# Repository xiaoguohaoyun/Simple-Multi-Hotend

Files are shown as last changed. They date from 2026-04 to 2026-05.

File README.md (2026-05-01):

# [Simple-Multi-Hotend]

[Simple-Multi-Hotend]是一种FDM3D打印多材料/多色解决方案。通过在打印打印过程中切换预热好的装载不同耗材的热端实现快速多材料打印。其目标是实现尽可能低成本且简单稳定的多材料打印，为了实现较高的适配性，热端切换只需要打印头XY轴运动就可实现，且切换结构与热端无关，可以通过修改热端固定件等实现其他热端的兼容。
打印头

QQ20260404-193802

---

## 核心特性
- **自动预热**：开启orcaslicer中的Ooze预防功能，会根据自己设定的预热时间提前在切换材料前插入预热命令，切换时释放旧热端并切换到待机温度然后抓取已经预热好的热端，若下一次切换的时间短于加热时间则保持温度不降温。
- **欠驱动切换机构**：采用欠驱动设计不需要额外增加主动元件，利用打印头自身的XY轴运动与停靠坞机械交互来实现热端切换和耗材丝夹紧松开。
- **磁吸麦克斯韦定位耦合机构**：热端模块锁定采用N52磁铁磁吸配合[麦克斯韦耦合](https://en.wikipedia.org/wiki/Kinematic_coupling)定位机构，打印头端有定位销组成的三个槽口，热端模块端有圆头销头部组成的球头。磁吸配合时实现对热端模块空间六自由度的限位，不存在过定位所以即使有加工装配误差以及磨损变形热端模块都能自适应消隙精确定位。
- **自动喷嘴偏移量校准**:采用喷嘴触碰校准器校准每个头XYZ轴相对T0的偏移量，参考[FoxChanger](https://github.com/Noisyfox/FoxChanger/tree/main/NozzleProbe)，需要清理干净喷嘴才能获得正确喷嘴偏移量。不需要每次打印前都校准，通常在刚装配好或者出现撞头等情况需要校准。

## 硬件与软件需求

### 硬件
* **打印机** 原理上支持打印头具有XY移动能力的机型（如voron2.4、voron三叉戟、大鱼TT等），本开源只提供打印头和基础停靠坞设计需要根据自己机型固定装载停靠坞的铝型材和其他兼容修改。
* **主板** 由于采用有线加热，每个热端模块具有一个加热片和热敏，可利用主板空余接口来扩展少量热端模块，若需要扩展更多热端模块需要制作[扩展板]( https://oshwhub.com/johnnybyzhang/f103-based-klipper-ext-can-usb)来增加主板的加热棒接口和热敏接口。

### 软件
* **固件** 整体热端切换通过klipper宏命令实现，若需使用喷嘴偏移量校准则需要下载[toolchange](https://github.com/viesturz/klipper-toolchanger)插件，配合自动校准宏来实现。
* **切片软件**：采用Orcaslicer，其他切片软件可自行探索。

## 组成概览

### 组成部分
- 打印头：有除了热端以外的其他部分
- 热端模块：包含热端，接有铁氟龙管和加热片和热敏的线
- 停靠坞：用于存放停靠的热端，可以堵住停靠热端的嘴防止漏料，以及有散热风扇给停靠的热端进行散热（无封箱的采用侧面离心风扇对所有热端进行散热、有封箱的采用每个停靠坞一个轴流风扇）。

### 零件
#### 打印版
- 1.5×5（直径*长）圆柱销：用于构成麦克斯韦耦合定位的槽（×6）
- 3×6（直径*长）圆头销：用于构成麦克斯韦耦合定位的球（一个热端3个）
- 5×20（直径*长）内螺纹圆头销：装配于停靠坞上用于撑开挤出机摆臂（一个停靠坞1个）
- 6×4（直径*厚）N52磁铁：用于吸附热端模块到打印头上和停靠坞上（一个热端3个，一个停靠坞1个，打印头3个）
- M3×6沉头螺丝
- M3×25螺丝
- M3×8螺丝
- M3×10螺丝
- M3×12螺丝
- M3×14螺丝
- M3×20螺丝
- M2.5×16螺丝
- M2×8螺丝
- M3×4×4热熔螺母
- HGX挤出机齿轮组
- 4020蜗轮风扇
- 2510轴流风扇
- 欧姆龙微动开关
- 10×2（宽×厚）自粘耐热硅胶条
#### CNC版
CNC件采用嘉立创打样制作（打样零件汇总在CAD文件夹里）
- 1.5×5（直径*长）圆柱销：用于构成麦克斯韦耦合定位的槽（×6）
- 3×5（直径*长）圆头销：用于构成麦克斯韦耦合定位的球（一个热端3个）
- 5×20（直径*长）内螺纹圆头销：装配于停靠坞上用于撑开挤出机摆臂（一个停靠坞1个）
- 6×4（直径*厚）N52磁铁：用于吸附热端模块到打印头上和停靠坞上（一个热端3个，一个停靠坞1个，打印头3个）
- M3×8沉头螺丝
- M3×25螺丝
- M3×8螺丝
- M3×10螺丝
- M3×12螺丝
- M3×14螺丝
- M3×20螺丝
- M2.5×16螺丝
- M2×8螺丝
- M4长10六角隔离柱
- M4长14六角隔离柱
- HGX挤出机齿轮组
- 4020蜗轮风扇
- 2510轴流风扇
- 欧姆龙微动开关
- 10×2（宽×厚）自粘耐热硅胶条
- M4*25带孔螺丝
- 内3外6厚2.5轴承（×2）

## 安装与配置指南

### printer.cfg
   Printer.cfg主体可以沿用自己以前的，参考我的printer.cfg里的格式和下面的提示修改，也可以直接用我的然后改成自己主板的引脚。
   1. 引用 toolchange.cfg 和 calibration.cfg。
   2. 仿照extruder1格式定义增加的热端，加热棒热敏引脚按自己主板接线来，共用E0的挤出机，其他的为虚拟挤出机。
   3. probe采用固定微动，开始打印时热端全部停放于停靠坞中用耐高温硅胶垫堵嘴，加热到目标温度才拿出来解决初始漏料问题，不需要擦嘴，调平时未抓取热端此时微动为打印头最低点。还未支持其他调平方式，建议直接参考我的probe相关配置包括网床和调平的配置（主要是增加了调平前释放抓取的热端）。
   4. 添加停靠坞散热风扇配置，停靠坞散热风扇和喉管冷却风扇关联的挤出机里添加所有挤出机。
   5. 修改打印开始gcode，实现打印前自动给要使用的热端进行挤出划线。
   6. 修改打印结束gcode，添加UNTOOL命令保证打印完自动卸载热端，让下次打印时不用自己手动取下热端。增加关闭所有热端加热命令。
### toolchange.cfg
   1. 添加toolchange.cfg。添加成功后仪表盘界面会出现T0、T1、T2以及、UNTOOL命令，（没调坐标先别点、会直接撞）点击T0是抓去T0，抓取T0后再点击T1坐标会自动卸载T0然后抓取T1，点击UNTOOL是卸载当前热端。
   2. 固定停靠坞以及调整停靠坞坐标：手动把热端装到打印头上，把打印头拖动到X轴最右边，再往前拖动，然后把第一个停靠坞固定在能刚好让热端锁定螺丝穿过停靠坞大孔的位置（这个位置即为第一个停靠坞的坐标），然后取下热端，点击全部归位，再把热端装到打印头上，慢慢移动打印头到刚才找到的停靠坞位置让锁定螺丝穿过停靠坞大孔，记下此时的坐标将其填入toolchange里T0的停靠坞位置，一个停靠坞占30mm宽度，其他停靠坞坐标用等差数列得到，如有误差可自己微调每一个停靠坞的坐标。 
   
   
   3. 正确设置坐标后，注释正常速度，解除测试速度注释，用慢速进行切换测试，（方便看到没对齐直接点急停）。
   4. 测试速度切换正常后，注释测试速度，解除正常速度注释（可以根据自己机器情况自己测试出更为合适的速度）。
### calibration.cfg
   1. 下载[toolchange](https://github.com/viesturz/klipper-toolchanger)插件
   1. 添加calibration.cfg
   2. 归位xyz，调平完成后，固定好校准器，点击T0抓去第一个热端，移动至喷嘴尖端刚好位于校准器中心正上方距离1mm左右，记下这个时候的坐标，填入calibration.cfg里校准器坐标处，然后还需要在里面自己定义一个停靠坞范围外的安全位置，防止校准的时候撞到停靠坞里的其他热端。
   3. 坐标设置好后输入 CALIBRATE_TOOL TOOL=_ 可以校准指定热端（需要先校准T0），输入 CALIBRATE_ALL_TOOLS 可以校准全部（需要设定好有哪些热端），校准完成会自动存储偏移量。
### orcaslicer
   1. 修改打印机gcode里起始和耗材丝更换gcode、设置更多挤出机、设置挤出机回抽。
- 打印起始Gcode：
```Gcode
   ; 让 OrcaSlicer 提取热床温度、初始喷嘴、用到的喷嘴列表及对应温度，发给打印机
PRINT_START BED=[bed_temperature_initial_layer_single] INITIAL_TOOL=[initial_tool] TOOLS="{if is_extruder_used[0]}0,{endif}{if is_extruder_used[1]}1,{endif}{if is_extruder_used[2]}2,{endif}{if is_extruder_used[3]}3,{endif}{if is_extruder_used[4]}4,{endif}" TEMPS="{if is_extruder_used[0]}{nozzle_temperature_initial_layer[0]},{endif}{if is_extruder_used[1]}{nozzle_temperature_initial_layer[1]},{endif}{if is_extruder_used[2]}{nozzle_temperature_initial_layer[2]},{endif}{if is_extruder_used[3]}{nozzle_temperature_initial_layer[3]},{endif}{if is_extruder_used[4]}{nozzle_temperature_initial_layer[4]},{endif}"
```
- 耗材更换Gcode：
```Gcode
M104 S{nozzle_temperature[next_extruder]} T{next_extruder}
T{next_extruder}
```
   2. 工艺栏里开启擦拭塔（如果料和参数调得好，且模型不涉及快速微小挤出，可以把模型拖到停靠坞旁边关掉擦料塔尝试无擦料塔打印）和自动预热（Ooze）。
   

## 注意事项
- 打印件采用abs打印，4层墙，60%填充。
- 挤出机弹簧不能拧太紧，过紧会导致摆臂转动的时候发生形变导致挤出轮张不开，具体情况视自己打印出摆臂的实际刚性而定。
- 为了减少热量传导效率，用到的TZ2.0热端需要去掉固定加热块的两个螺丝，仅靠侧面顶丝固定。

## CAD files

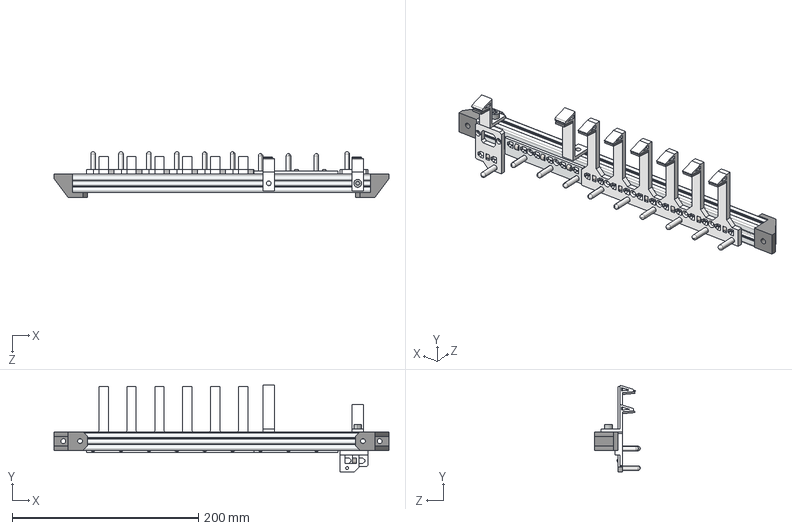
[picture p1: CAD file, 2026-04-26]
CAD/停靠坞集合.STEP
360.0 x 93.1 x 49.0 mm
停靠坞（中置）堵嘴
LE-6-2020铝型材[LE-6-2020-B-OO-318]_LE-6-2020-B-OO-240
不锈钢内螺纹圆弧销 x 10
停靠坞横杆固定 x 2
停靠坞（中置）打印
停靠坞（中置）CNC
耐热硅胶垫 x 8
热端停靠坞改
N52磁铁 6 4 x 10
堵头固定件
圆柱头螺栓_M5*8

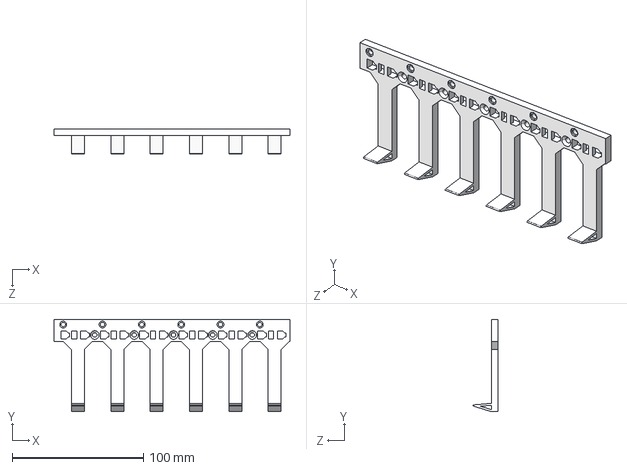
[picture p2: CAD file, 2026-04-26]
CAD/热端停靠坞打印.STEP
180.0 x 70.5 x 18.9 mm

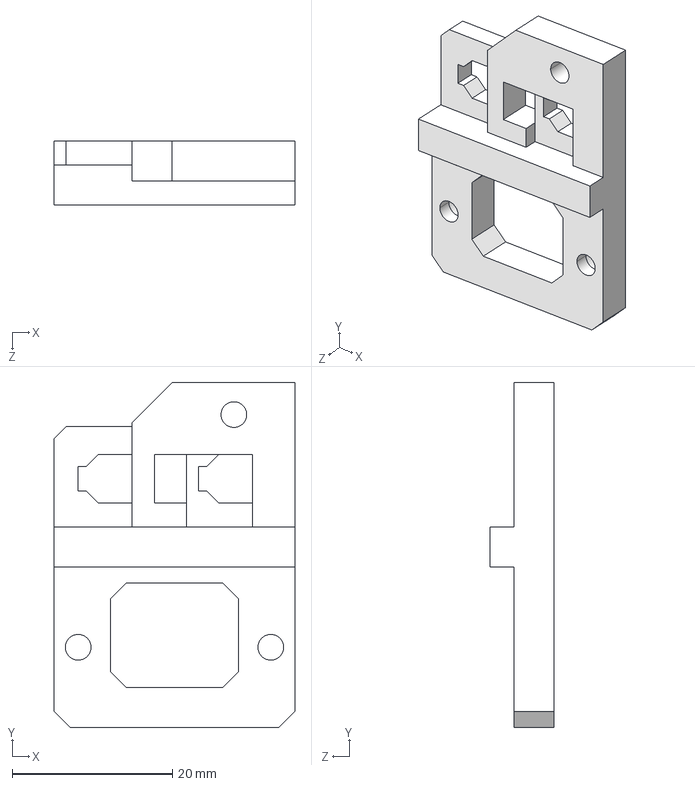
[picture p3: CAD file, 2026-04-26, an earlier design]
CAD/热端停靠坞打印旧.STEP
30.0 x 43.0 x 8.00 mm

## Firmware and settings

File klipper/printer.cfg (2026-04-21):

#####################################################################
#                               文件调用                               #
#####################################################################
[include fluidd.cfg]          # FLUIDD调用文件。
#[include mainsail.cfg]        # MAINSDIL调用文件。
[include toolchange.cfg]
[include calibration.cfg]
#[include plr.cfg]
#####################################################################
#                               主板配置                               #
#####################################################################
[mcu]
serial: /dev/serial/by-id/usb-Klipper_stm32h723xx_12345-if00
[mcu host]
serial: /tmp/klipper_host_mcu

#####################################################################
#                            副板扩展配置                             #
#####################################################################
[mcu expander]
# 这里填入你在第一步获取到的新主板ID
serial: /dev/serial/by-id/usb-Klipper_stm32f072xb_3F0035000357465036383420-if00 
#####################################################################
#                            机型和加速度                            #
#####################################################################
[printer]                       # 打印机设置
kinematics: corexy              # 运动学结构分为：笛卡尔和corexy等等。笛卡尔：cartesian
max_velocity: 600               # 打印机最大速度   
max_accel: 30000                 # 最大加速度 
max_z_velocity: 30              # z轴最大速度
max_z_accel: 300                # z轴最大加速度
square_corner_velocity: 5.0     # 方形拐角速度，小一点可以有效避免平台重带来的惯性
#####################################################################
#                             温度监控                               #
#####################################################################
[temperature_sensor FLY-Pi]
sensor_type: temperature_host

#[temperature_sensor Fly-C8p]     # FLY主板温度（可自行重命名）
#sensor_type: temperature_mcu     # 关联mcu（默认）

# [temperature_sensor Box]          # 箱内温度温度 （需要增加一颗温感,参考配置）
# sensor_type: ATC Semitec 104GT-2  # 传感器型号
# sensor_pin: PA4                   # 信号接口

#####################################################################
#             X/Y步进电机设置 (X/Y Stepper Settings)                 # 
#####################################################################
#   B Motor ---- Motor A 
#   |                  |
#   |------挤出机-------|
#   |                  |
#   |                  |
#          正前方   
#####################################################################
#                  X 轴步进电机 (B Motor)                            #
#####################################################################
[stepper_x]
step_pin: PE5                       # X轴电机脉冲引脚设置
dir_pin: !PA8                        # X轴电机运行引脚设置,方向按实际判断，加感叹号会让运行方向反转
enable_pin: !PA15                   # X轴电机使能引脚设置,使能引脚需要加感叹号，否者电机不工作
rotation_distance: 40               # 主动带轮周长mm（2GT-20T带轮40，2GT-16T带轮32）
microsteps: 64                      # 电机细分设置，细分越高，质量越高，但主控负荷越大
full_steps_per_rotation: 200        # 电机单圈所需脉冲数（1.8度电机:200，0.9度电机:400）
endstop_pin:tmc2209_stepper_x:virtual_endstop                   # 限位开关PIN脚,建议常闭然后添加！反转状态,位置在io-3 !PB3 
position_min: -10                     # X轴的最小行程
position_endstop: 245            # 限位开关的位置 (250mm-300mm-350mm)
position_max: 245                   # X轴的最大行程 (250mm-300mm-350mm)
homing_speed: 50                    # 复位速度，最大为100.归位速度建议别太快
homing_retract_dist: 0              # 第一次触发复位开关之后的后退距离
#--------------------------------------------------------------------
[tmc2209 stepper_x]                 # X 驱动配置 -TMC2209
uart_pin: PC9                       # 通讯端口Pin脚定义
interpolate: False                  # 否开启256微步插值，建议关闭（开启是True，关闭是False）
run_current: 1.2                   # 电机运行电流值（单位：mA）
sense_resistor: 0.110               # 驱动采样电阻不要改
driver_SGTHRS:90
diag_pin:^PD9
#stealthchop_threshold: 100          # 静音阀值（如果不需要静音，请将数值改为0）
#####################################################################
#                  Y 轴步进电机 (A Motor)                            #
#####################################################################
[stepper_y]
step_pin: PE4                       # Y轴电机脉冲引脚设置
dir_pin: PC11                      # Y轴电机运行引脚设置,方向按实际判断，加感叹号会让运行方向反转
enable_pin: !PC12                   # Y轴电机使能引脚设置,使能引脚需要加感叹号，否者电机不工作
rotation_distance: 40               # 主动带轮周长mm（2GT-20T带轮40，2GT-16T带轮32）
microsteps: 64                      # 电机细分设置，细分越高，质量越高，但主控负荷越大
full_steps_per_rotation: 200        # 电机单圈所需脉冲数（1.8度电机:200，0.9度电机:400）
endstop_pin:^!PD10
position_min: -33                   # Y轴的最小行程
position_endstop: 229               # 限位开关的位置 (250mm-300mm-350mm)
position_max: 229                   # Y轴的最大行程 (250mm-300mm-350mm)
homing_speed: 50                    # 复位速度，最大为100        归位速度建议别太快
homing_retract_dist: 5              # 第一次触发复位开关之后的后退距离 5
#--------------------------------------------------------------------
[tmc2209 stepper_y]                 # Y驱动配置 -TMC2209
uart_pin: PC10                      # 通讯端口Pin脚定义
interpolate: false                  # 否开启256微步插值，建议关闭（开启是True，关闭是False）
run_current: 1.2                    # 电机运行电流值（单位：mA）
sense_resistor: 0.110               # 驱动采样电阻不要改
diag_pin:^PD8
#stealthchop_threshold: 100          # 静音阀值（如果不需要静音，请将数值改为0）
#####################################################################
#                           Z轴步进电机                              #
#####################################################################
##    Z步进电机 - 左前方
[stepper_z]
step_pin: PE3                 # z轴电机脉冲引脚设置
dir_pin:  !PD1                 # z轴电机方向引脚设置,方向引脚需要按实际判断，加感叹号会让运行方向反转
enable_pin: !PD2               # z轴电机使能引脚设置,使能引脚需要加感叹号，否者电机不工作
rotation_distance: 8          # 丝杆导程为 8，请根据你的实际使用情况修改，总共需要修改3处
full_steps_per_rotation: 200  # 电机单圈所需脉冲数（1.8度电机:200，0.9度电机:400)
microsteps: 64                # 电机细分设置,细分越高，质量越高，但主控负荷越大
endstop_pin: probe:z_virtual_endstop            # 限位开关PIN脚,建议常闭然后添加！反转状态,位置在io-1
position_min: -10             # Z轴的最小行程（配置喷嘴清洁需要-5左右）
position_max: 180             # Z轴的最大行程 (250mm-300mm-350mm)
homing_speed: 10               # 复位速度-最大 20
second_homing_speed: 3        # 二次复位速度-最大 10
homing_retract_dist: 3        # 后撤距离
#--------------------------------------------------------------------
[tmc2208 stepper_z]
uart_pin: PD0                 # 驱动通信端口
interpolate: false            # 微步插值256
run_current: 0.8              # 运行电流mA
sense_resistor: 0.110         # 驱动采样电阻不要改
stealthchop_threshold: 500    # 静音阀值（如果不需要静音，请将数值改为0）
#--------------------------------------------------------------------
##    Z1 步进电机 - 后方
[stepper_z1]
step_pin: PE2                # z1轴电机脉冲引脚设置
dir_pin:  !PD4               # z1轴电机方向引脚设置,方向引脚需要按实际判断，加感叹号会让运行方向反转
enable_pin: !PD5              # z1轴电机使能引脚设置,使能引脚需要加感叹号，否者电机不工作
rotation_distance: 8          # 丝杆导程为 8
full_steps_per_rotation: 200  # 电机单圈所需脉冲数（1.8度电机:200，0.9度电机:400
microsteps: 64                # 电机细分设置,细分越高，质量越高，但主控负荷越大
#--------------------------------------------------------------------
[tmc2208 stepper_z1]
uart_pin: PD3               # 驱动通信端口
interpolate: false            # 微步插值256
run_current: 0.8              # 运行电流mA
sense_resistor: 0.110         # 驱动采样电阻不要改
stealthchop_threshold: 500    # 静音阀值（如果不需要静音，请将数值改为0）
#--------------------------------------------------------------------
##    Z2 步进电机 - 右前方
[stepper_z2]
step_pin: PE7                 # z2轴电机脉冲引脚设置
dir_pin: !PE11               # z2轴电机方向引脚设置,方向引脚需要按实际判断，加感叹号会让运行方向反转
enable_pin: !PE10             # z2轴电机使能引脚设置,使能引脚需要加感叹号，否者电机不工作
rotation_distance: 8          # 丝杆导程为 8
full_steps_per_rotation: 200  # 电机单圈所需脉冲数（1.8度电机:200，0.9度电机:400
microsteps: 64                # 电机细分设置,细分越高，质量越高，但主控负荷越大
#--------------------------------------------------------------------
[tmc2208 stepper_z2]
uart_pin: PC15                # 驱动通信端口
interpolate: false            # 微步插值256
run_current: 0.8              # 运行电流mA
sense_resistor: 0.110         # 驱动采样电阻不要改
stealthchop_threshold: 500    # 静音阀值（如果不需要静音，请将数值改为0）
#####################################################################
#                     E0 挤出机设置 （E0 Settings）                   # 
#####################################################################
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

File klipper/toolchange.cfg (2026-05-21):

[save_variables]
filename: ~/printer_data/config/myvariables.cfg

[delayed_gcode RESTORE_TOOL_STATUS]
initial_duration: 0.1
gcode:
    {% set svv = printer.save_variables.variables %}
    {% if svv.current_tool is defined %}
        SET_GCODE_VARIABLE MACRO=_tool_status VARIABLE=current_tool VALUE={svv.current_tool}
        # 可选：如果你的换刀逻辑包含其他操作（如设置温度、抬升Z轴等），可以在这里补充
    {% endif %}
#=================================================
# 1. 参数集中管理
#=================================================
[gcode_macro _toolchanger_cfg]
description: 工具切换参数配置

# --- 换刀抬升与速度与加速度 ---
variable_z_hop:            0.4   # 换头抬升高度
variable_feed_z:           600   # 抬升速度
variable_feed_fast:        24000 # 工作速度（空驶）
#variable_feed_fast:       2000  # 测试速度
variable_feed_slow:        4000  # 工作速度（受力）
variable_accel_toolchange: 10000  # 换头时的加速度 

# --- 换刀回抽/清洗配置 ---
variable_swap_retract_len: 0   # [A] 释放回抽：放回底座时抽多少
variable_swap_prime_len:   0   # [B] 抓取清洗：抓取时挤出多少
variable_swap_retract_spd: 1000

# ========================================================
# 【停靠坞运动逻辑参数】
# ========================================================
variable_dock_shift_x: -3.5   # 横移开挤出机距离
variable_dock_dodge_y: 16     # 避让动作的 Y 轴相对位移
variable_dock_safe_y:  25     # 安全拔出的 Y 轴相对位移

#---------------------------------------------------------
# 各热端参数配置
#---------------------------------------------------------
# T0 配置
variable_t0_dock_x: 244       # T0 热端进入停靠坞大孔X坐标
variable_t0_dock_y: -24       # T0 热端进入停靠坞大孔Y坐标

# T1 配置
variable_t1_dock_x: 214     
variable_t1_dock_y: -24

# T2 配置
variable_t2_dock_x: 184
variable_t2_dock_y: -24

# T3 配置
variable_t3_dock_x: 154
variable_t3_dock_y: -24

gcode:

#=================================================
# 2. 切换热端命令（根据自己的热端数添加对应数量）
#=================================================
[gcode_macro T0]     #输入T0，当前有热端则卸载当前热端抓取T0，无热端则直接抓取T0
gcode: change_tool T=0

[gcode_macro T1]
gcode: change_tool T=1

[gcode_macro T2]
gcode: change_tool T=2

[gcode_macro T3]
gcode: change_tool T=3

[gcode_macro UNTOOL]  #卸载当前热端
gcode: change_tool T=-1

#=================================================
# 3. 状态变量（记录当前抓取头）
#=================================================
[gcode_macro _tool_status]
variable_current_tool: -1
gcode:

#=================================================
# 4. 释放热端
#=================================================
[gcode_macro _release_tool]
gcode:
    {% set cfg = printer["gcode_macro _toolchanger_cfg"] %}
    {% set tool = params.TOOL|int %}
    {% set prefix = "t" ~ tool %}
    {% set active_extruder = printer.toolhead.extruder %}
    
    # 获取当前喷头的核心点坐标和相对位移
    {% set dock_x = cfg[prefix + "_dock_x"] %}
    {% set dock_y = cfg[prefix + "_dock_y"] %}
    {% set shift_x = cfg.dock_shift_x %}
    {% set dodge_y = cfg.dock_dodge_y %}
    {% set safe_y  = cfg.dock_safe_y %}

    {% set msg = "正在放回 T%d" % tool %}   M118 {msg}

    # --- [A] 释放回抽 (防止底座溢料) ---
    {% set cur_temp = printer[active_extruder].temperature|float %}
    {% set min_temp = printer.configfile.settings[active_extruder].min_extrude_temp|default(170)|float %}
    {% if cur_temp >= min_temp %}
       M83  
       G1 E-{cfg.swap_retract_len} F{cfg.swap_retract_spd} 
       #G4 P100
       #M400 
    {% else %}
       M118 温度不足({cur_temp})，跳过释放回抽。
    {% endif %}

    # --- 开始释放动作 (抓取动作的逆序) ---
    G90 
    # 1. 带热端走到到X轴对准停靠坞大孔，Y轴位于停靠坞外（停靠坞入口）
    G0 X{dock_x} Y{dock_y + safe_y} F{cfg.feed_fast}
    
    # 2. 带热端Y轴移动完全进入停靠坞
    G0 X{dock_x} Y{dock_y} F{cfg.feed_fast}
    #G4 P100
    #M400
    
    # 3. 横移打开挤出机摆臂
    G0 X{dock_x + shift_x} Y{dock_y} F{cfg.feed_slow}
    
    # 4. 打印头离开停靠坞拔开与打印头磁吸锁定的热端
    G0 X{dock_x + shift_x} Y{dock_y + dodge_y} F{cfg.feed_slow}
    
    # 5. 反向横移闭合挤出机摆臂
    G0 X{dock_x} Y{dock_y + dodge_y} F{cfg.feed_slow}
    
    # 6. 完全离开停靠坞（停靠坞入口）
    G0 X{dock_x} Y{dock_y + safe_y} F{cfg.feed_fast}
    #G4 P100
    #M400

#=================================================
# 5. 抓取热端
#=================================================
[gcode_macro _pickup_tool]
gcode:
    {% set cfg = printer["gcode_macro _toolchanger_cfg"] %}
    {% set tool = params.TOOL|int %}
    {% set prefix = "t" ~ tool %}
    {% set current_heater = "extruder" if tool == 0 else ("extruder" ~ tool) %}
    
    # 获取当前喷头的核心点坐标和相对位移
    {% set dock_x = cfg[prefix + "_dock_x"] %}
    {% set dock_y = cfg[prefix + "_dock_y"] %}
    {% set shift_x = cfg.dock_shift_x %}
    {% set dodge_y = cfg.dock_dodge_y %}
    {% set safe_y  = cfg.dock_safe_y %}

    {% set msg = "【抓取】正在抓取 T%d" % tool %}   M118 {msg}
    
    # --- 开始抓取动作 ---
    G90
    # 1. 到达停靠坞入口
    G0 X{dock_x} Y{dock_y + safe_y} F{cfg.feed_fast}
    
    # 2. Y轴前进到避让位置（让摆臂能摸到摆臂撑杆，同时打印头不撞到停靠的热端）
    G0 X{dock_x} Y{dock_y + dodge_y} F{cfg.feed_fast}
    
    # 3. 横移开挤出机
    G0 X{dock_x + shift_x} Y{dock_y + dodge_y} F{cfg.feed_slow}
    
    # 4. Y轴移动完全进入停靠坞（打印头与热端磁吸结合）
    G0 X{dock_x + shift_x} Y{dock_y} F{cfg.feed_slow}
    #G4 P100
    #M400
    
    # 5. 反向横移闭合挤出机夹紧耗材丝
    G0 X{dock_x} Y{dock_y} F{cfg.feed_slow}
    
    # <<< 停靠坞内挤出补偿 >>>
    {% set cur_temp = printer[current_heater].temperature|float %}
    {% set min_temp = printer.configfile.settings[current_heater].min_extrude_temp|default(170)|float %}
    {% if cur_temp >= min_temp %}
         M83 
         G1 E{cfg.swap_prime_len} F{cfg.swap_retract_spd} 
         #G4 P100
         #M400
    {% else %}
         M118 温度不足({cur_temp})，跳过抓取处理。
    {% endif %}

    # 6. 完全离开停靠坞（停靠坞入口）
    G0 X{dock_x} Y{dock_y + safe_y} F{cfg.feed_fast}
    #G4 P100
    #M400
     
#=================================================
# 6. 主切换宏
#=================================================
[gcode_macro change_tool]
gcode:
    {% set new_tool = params.T|default(-1)|int %}
    {% set old_tool = printer["gcode_macro _tool_status"].current_tool|int %}
    {% set cfg = printer["gcode_macro _toolchanger_cfg"] %}

    {% if new_tool == old_tool %}
        M118 目标状态与当前一致(T{new_tool})，无需操作。
    {% else %}
        {% if new_tool == -1 %}
            M118 收到卸载指令：正在卸载 T{old_tool} ...
        {% else %}
            M118 切换工具: T{old_tool} -> T{new_tool}
        {% endif %}

        #保存换头前状态
        SAVE_GCODE_STATE NAME=tool_change

        # 记录当前系统打印加速度，并设置为换头加速度
        {% set saved_accel = printer.toolhead.max_accel %}
        SET_VELOCITY_LIMIT ACCEL={cfg.accel_toolchange}

        #换头前屏蔽断料检测
        #SET_FILAMENT_SENSOR SENSOR=tool_sensor ENABLE=0
        
        #抬升
        G91
        G0 Z{cfg.z_hop} F{cfg.feed_z}
        G90
        
        #清除偏移偏移量采用统一的停靠坞坐标
        SET_GCODE_OFFSET X=0 Y=0 Z=0

        #释放旧工具
        {% if old_tool != -1 %}
            _release_tool TOOL={old_tool}
        {% else %}
            M118 当前无工具，跳过释放。
        {% endif %}

        #抓取新工具
        {% if new_tool != -1 %}
            {% set next_heater = "extruder" if new_tool == 0 else ("extruder" ~ new_tool) %}
            {% set target_temp = printer[next_heater].target|float %}
            {% if target_temp > 0 %}
                {% if printer[next_heater].temperature < (target_temp - 2) %}
                    M118 T{new_tool} 预热中...
                    TEMPERATURE_WAIT SENSOR={next_heater} MINIMUM={target_temp}
                {% endif %}
            {% endif %}

            _pickup_tool  TOOL={new_tool}
        {% else %}
            M118 工具已卸载。
        {% endif %}

        #更新状态变量
        SET_GCODE_VARIABLE MACRO=_tool_status VARIABLE=current_tool VALUE={new_tool}

        #恢复到换头前位置
        #RESTORE_GCODE_STATE NAME=tool_change MOVE=1 MOVE_SPEED=400
        RESTORE_GCODE_STATE NAME=tool_change MOVE=0 
        # 【新增】恢复打印时的原主加速度
        SET_VELOCITY_LIMIT ACCEL={saved_accel}

        # ==========================================
        # 应用喷嘴偏移量 (纯外置变量读取逻辑)
        # ==========================================
        {% if new_tool != -1 %}
            {% set svv = printer.save_variables.variables %}
            
            # 使用字符串拼接键名，直接从 svv 中读取，若不存在则 default 为 0.0
            {% set off_x = svv["t" ~ new_tool ~ "_offset_x"] | default(0.0) | float %}
            {% set off_y = svv["t" ~ new_tool ~ "_offset_y"] | default(0.0) | float %}
            {% set off_z = svv["t" ~ new_tool ~ "_offset_z"] | default(0.0) | float %}
            
            SET_GCODE_OFFSET X={off_x} Y={off_y} Z={off_z} MOVE=0
            { action_respond_info("T" ~ new_tool ~ " 加载校准值: X=" ~ off_x ~ " Y=" ~ off_y ~ " Z=" ~ off_z) }
        {% endif %}

        #换头后断料检测
        # {% if new_tool != -1 %}
        #     M400     ; 强制等待机器走完所有的抓取和恢复物理坐标动作
        #     #G4 P200  ; 停顿 0.2 秒
        #     _VERIFY_TOOL_AND_ENABLE_SENSOR ; 调用独立子宏进行判定
        # {% endif %}
        # 如果 new_tool 是 -1 (UNTOOL卸载)，就不进行检测，保持传感器关闭即可。

        SAVE_VARIABLE VARIABLE=current_tool VALUE={new_tool}

    {% endif %}
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
